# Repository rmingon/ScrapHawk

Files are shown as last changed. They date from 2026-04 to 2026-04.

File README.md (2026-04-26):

# ScrapHawk

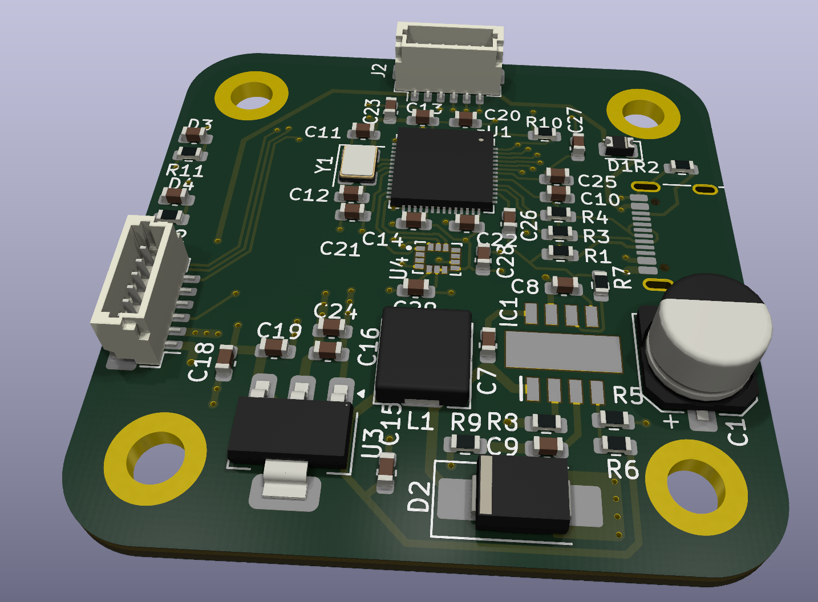
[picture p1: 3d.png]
ScrapHawk Hero Image


*Ultra-budget, high-performance RP2040 flight controller stack bypassing expensive legacy silicon.*

## The Concept: Rethinking the Flight Controller

For years, custom flight controllers have relied on expensive, legacy single-core silicon. ScrapHawk takes a radically different approach. By utilizing the ultra-affordable Raspberry Pi RP2040, modern FreeRTOS Symmetric Multiprocessing (SMP), and hardware-level Programmable I/O (PIO), ScrapHawk delivers a zero-latency, high-performance flight stack on a hacker's budget.

Beyond the silicon, ScrapHawk solves one of the most frustrating problems in drone engineering: Electromagnetic Interference (EMI) from high-current motor ESCs disrupting sensitive navigation sensors. 

To combat this, the ScrapHawk architecture is physically decoupled into two separate printed circuit boards connected by a 6-pin JST-SH (1.0mm) umbilical cable.

---

## Software Architecture: Multi-Core RTOS & PIO Offloading

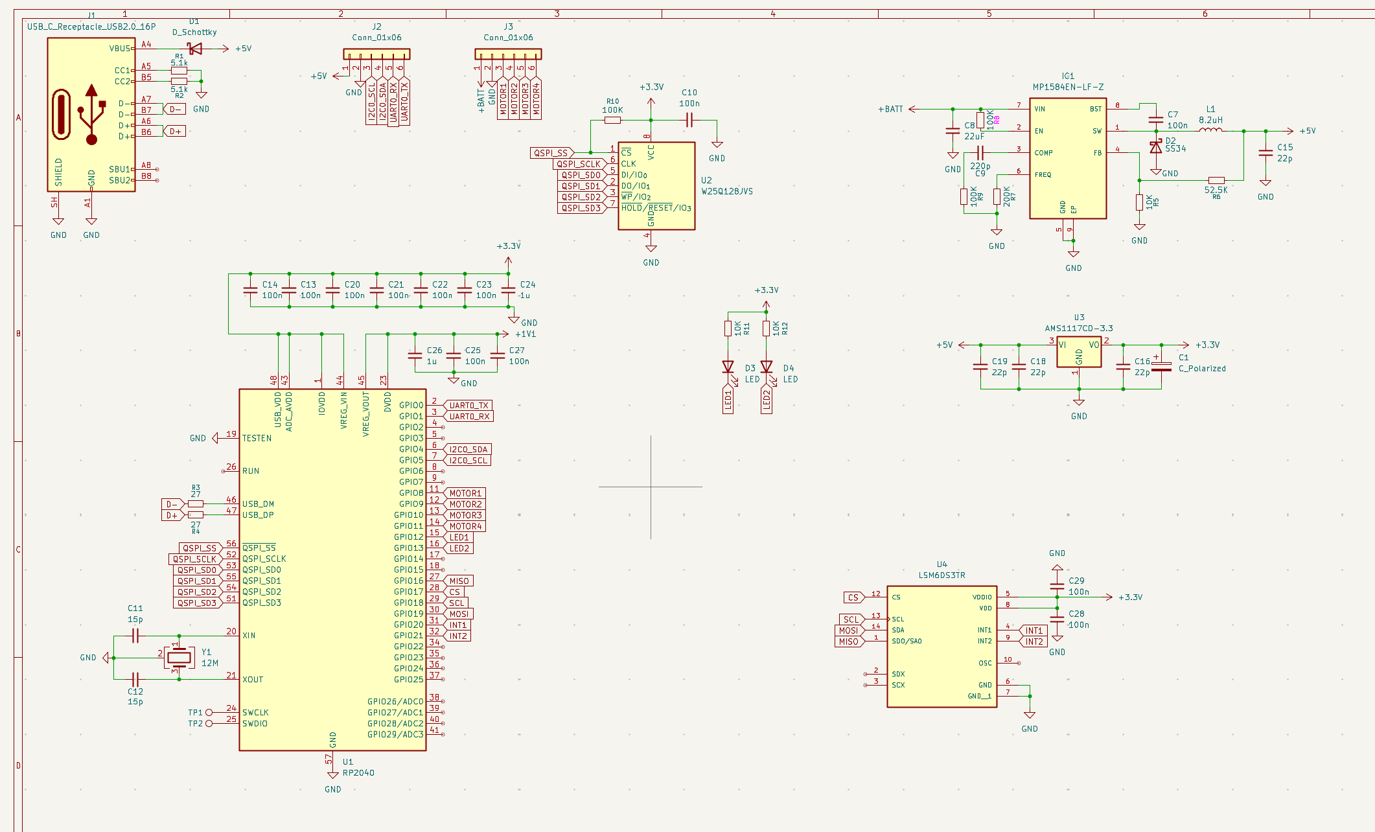
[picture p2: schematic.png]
Software Architecture Diagram


The RP2040 features dual Cortex-M0+ cores. Instead of treating this as a generic processing pool, ScrapHawk leverages FreeRTOS SMP to rigidly enforce core affinity, completely decoupling the real-time flight dynamics from slower, blocking navigation tasks.

### PIO: Zero-Latency Motor Control
Traditionally, generating DSHOT signals for ESCs requires complex timer/DMA configurations that eat up CPU cycles. ScrapHawk completely bypasses the CPU for motor control. By mapping the motor output pins to the RP2040's hardware PIO state machines, the DSHOT timing is handled independently at the hardware level. Core 0 simply pushes throttle values into a FIFO buffer, and the PIO hardware seamlessly clocks out the precise DSHOT pulses.

---

## Hardware Architecture: Split-Board Design

### Board 1: Main FC (The Brain & Muscle)
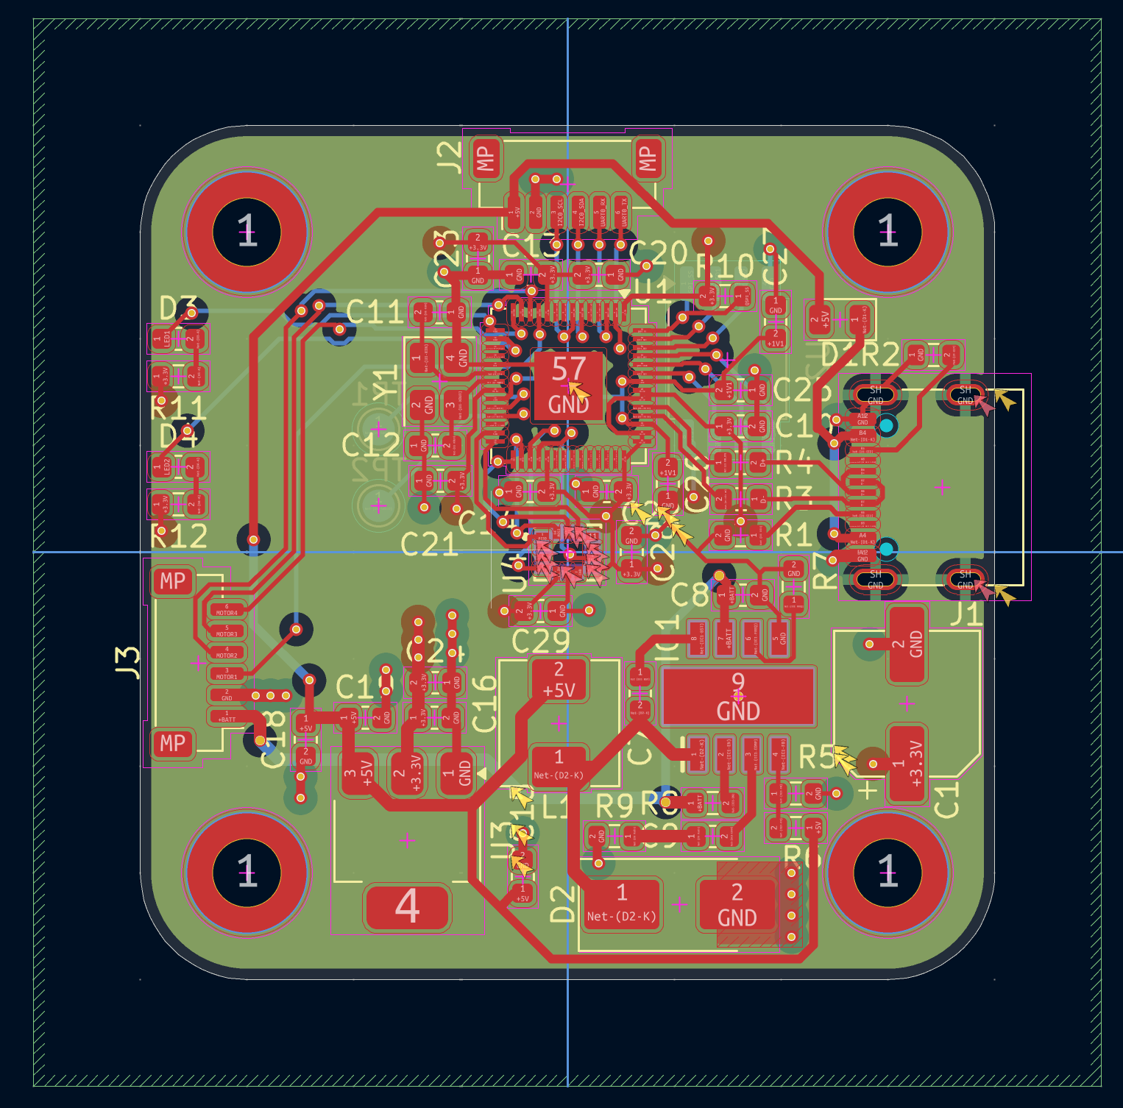
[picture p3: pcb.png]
Main FC Board Render


This is the core flight management and power delivery board, situated in the center of the drone frame.
* **MCU:** Raspberry Pi RP2040 (QFN-56) paired with 16MB QSPI Flash (Winbond W25Q128JVSIQ).
* **IMU:** STMicroelectronics LSM6DS3TR-C, placed precisely at the physical center of the PCB for accurate rotational data. Routed via SPI0 with Data Ready Interrupts.
* **Power Delivery:** A robust dual-stage filter ensures clean power despite ESC noise. A massive 470uF 35V Low-ESR input capacitor feeds a 5V Buck Converter (MP1584EN, 10uH inductor), which then feeds a 3.3V LDO (AMS1117-3.3).
* **Motor & Receiver I/O:** 4 corner ESC solder pads driven by PIO (GPIO 10-13), plus a dedicated 4-pin header for ExpressLRS 2.4GHz receivers via UART1.
* **Connectivity:** USB-C with proper dual 5.1kΩ pull-downs and 27Ω D+/D- series resistors. 
* **The Umbilical:** A 6-pin right-angle SMD connector carrying 5V, GND, UART0 (for GPS), and I2C0 (for Compass). It crucially includes 2.2kΩ pull-up resistors on the I2C lines to maintain signal integrity over the physical wire capacitance.

### Board 2: Nav Puck (The Senses)
Nav Puck Board Render

Designed to be mounted high on a mast, this board keeps the magnetometer and GPS completely isolated from the EMI generated by the motors and power leads.
* **Clean Local Power:** Receives 5V from the umbilical, which is filtered again through a localized AMS1117-3.3 LDO to provide exceptionally clean power exclusively for the sensors.
* **GPS:** Zhongke Micro ATGM336H-5N (UART) equipped with a U.FL connector for an active ceramic patch antenna. It includes an onboard MS621FE 3V backup battery to retain ephemeris data for instant hot-starts.
* **Compass:** QST QMC5883L (I2C) for precise, noise-free heading data.

---

## Who is this for?
ScrapHawk is designed for drone hardware hackers, custom flight controller developers, and FreeRTOS engineers who want to explore modern RTOS paradigms and PIO capabilities without being locked into expensive, proprietary, or legacy ecosystems. It proves that with clever software engineering and thoughtful hardware isolation, cheap silicon can fly just as well—if not better—than the expensive alternatives.

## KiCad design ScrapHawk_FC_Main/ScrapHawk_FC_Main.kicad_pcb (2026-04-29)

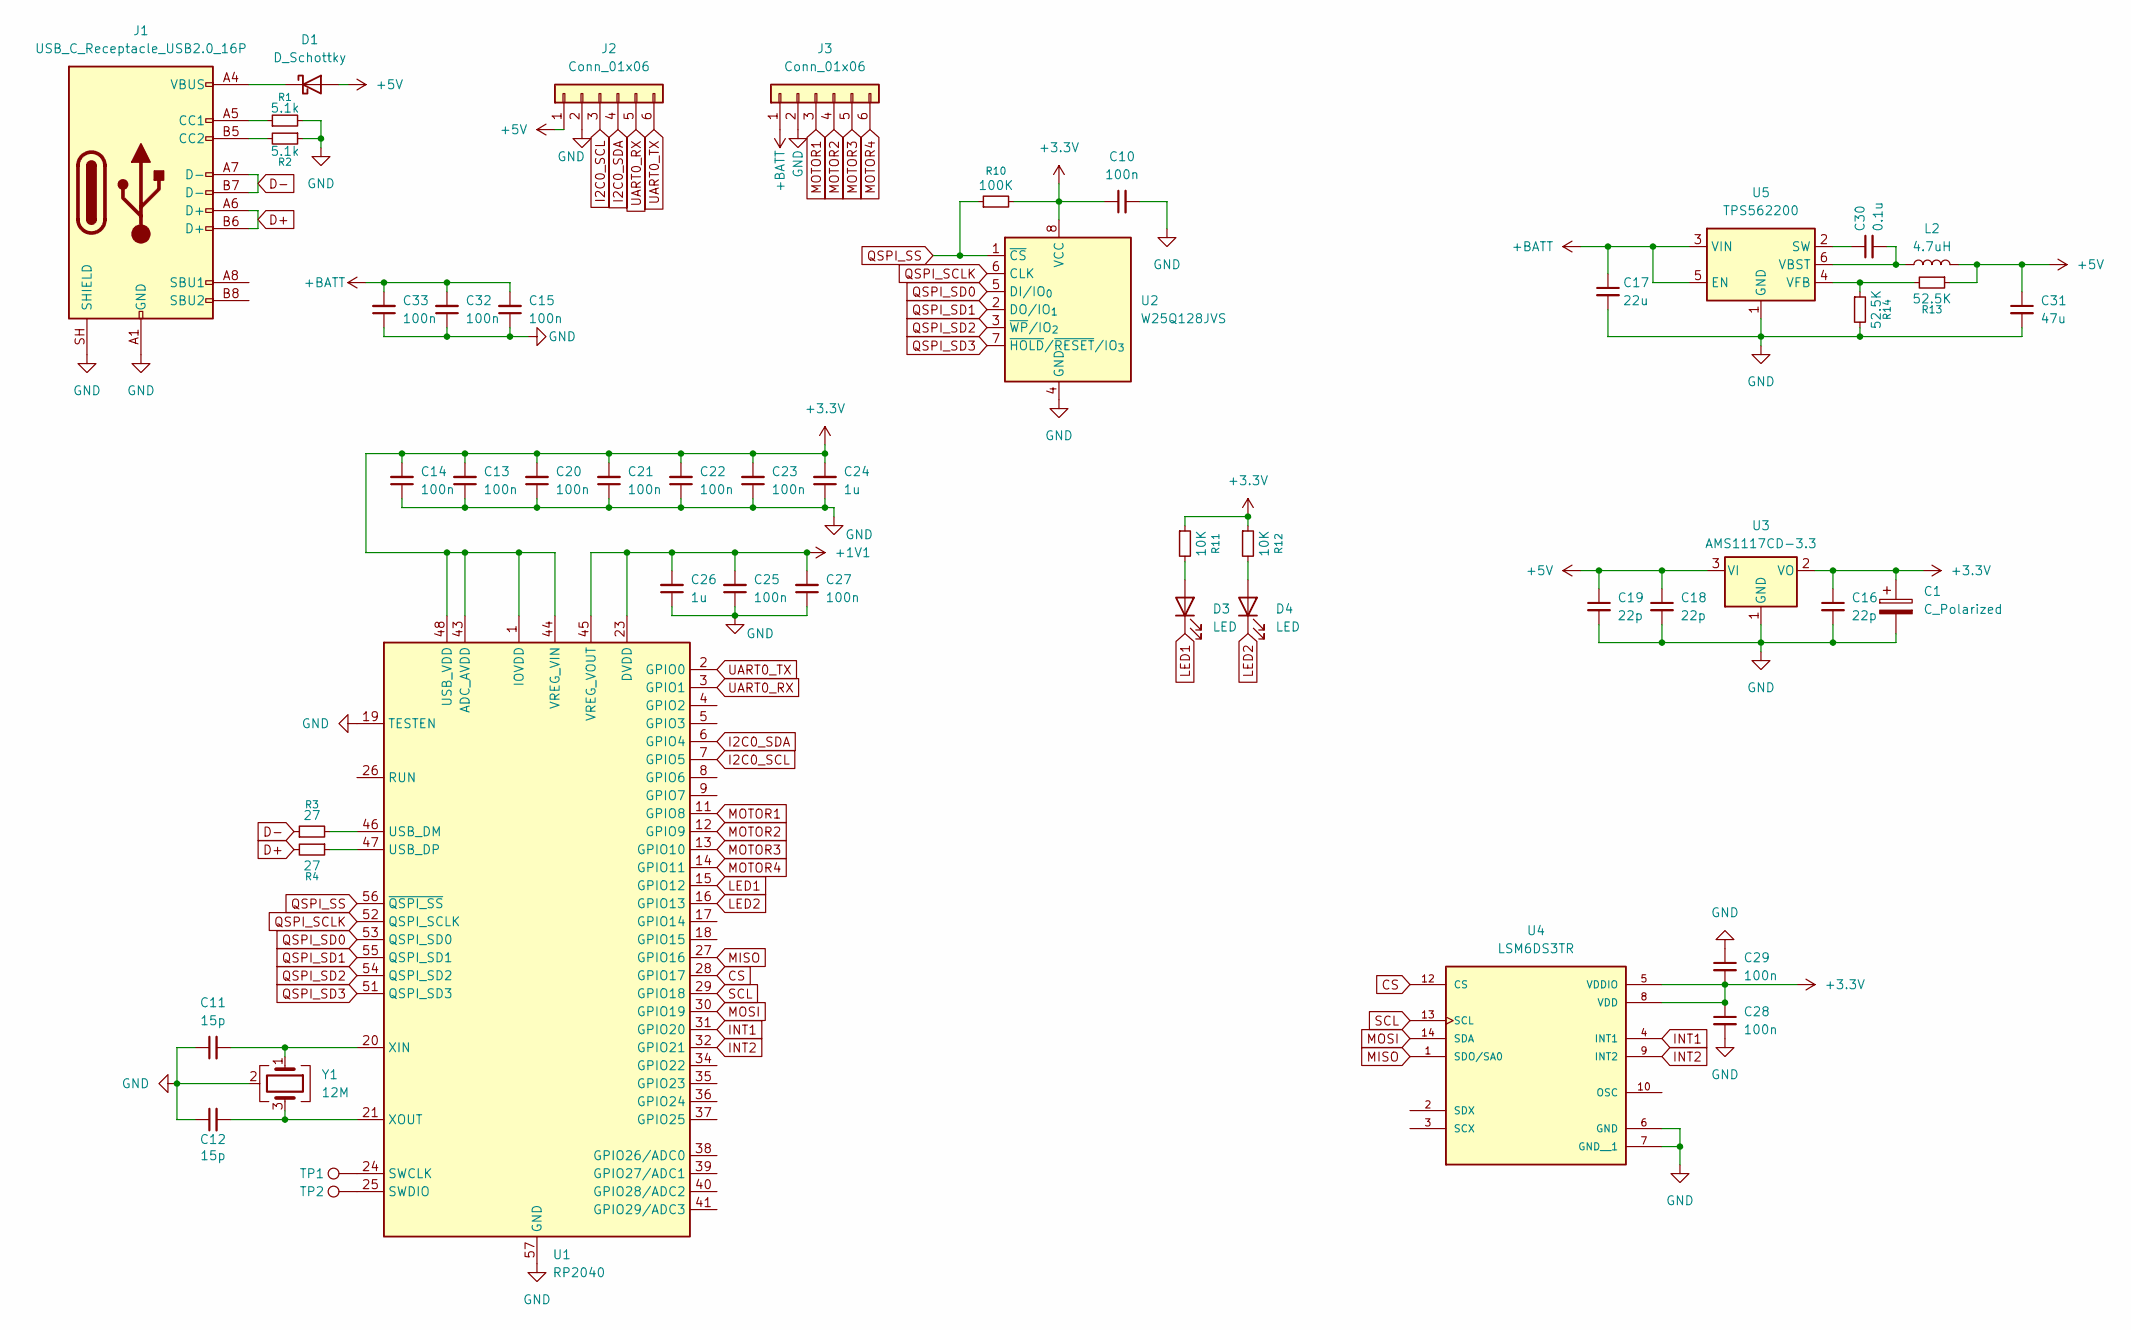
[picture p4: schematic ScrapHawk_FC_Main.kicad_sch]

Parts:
C1: C_Polarized; CP_Elec_6.3x5.2
C10, C13, C14, C20, C21, C22, C23, C25, C27, C28, C29: 100n; C_0603_1608Metric
C11, C12: 15p; C_0603_1608Metric
C15, C32, C33: 100n; C_1206_3216Metric
C16, C18, C19: 22p; C_0603_1608Metric
C17: 22u; C_0603_1608Metric
C24, C26: 1u; C_0603_1608Metric
C30: 0.1u; C_0603_1608Metric
C31: 47u; C_0603_1608Metric
D1: D_Schottky; D_0805_2012Metric
D3, D4: LED; C_0603_1608Metric
J1: USB_C_Receptacle_USB2.0_16P; USB_C_Receptacle_G-Switch_GT-USB-7010ASV
J2, J3: Conn_01x06; JST_SH_BM06B-SRSS-TB_1x06-1MP_P1.00mm_Vertical
L2: 4.7uH; L_Chilisin_BMRA00050520
R1, R2: 5.1k; R_0603_1608Metric
R3, R4: 27; R_0603_1608Metric
R10: 100K; R_0603_1608Metric
R11, R12: 10K; R_0603_1608Metric
R13, R14: 52.5K; R_0603_1608Metric
TP1, TP2: TestPoint; TestPoint_Pad_D1.5mm
U1: RP2040; QFN-56-1EP_7x7mm_P0.4mm_EP3.2x3.2mm
U2: W25Q128JVS; SOIC-8_5.3x5.3mm_P1.27mm
U3: AMS1117CD-3.3; SOT-223
U4: LSM6DS3TR; PQFN50P300X250X86-14N; PARTREV 2
U5: TPS562200; SOT-23-6
Y1: 12M; Crystal_SMD_SeikoEpson_TSX3225-4Pin_3.2x2.5mm

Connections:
+1V1: C25.2, C26.2, C27.2, U1.23 (DVDD), U1.45 (VREG_VOUT), U1.50 (DVDD)
+3.3V: C1.1, C10.1, C13.2, C14.2, C16.1, C20.2, C21.2, C22.2, C23.2, C24.2, C28.1, C29.2, R10.2, R11.1, R12.1, U1.1 (IOVDD), U1.10 (IOVDD), U1.22 (IOVDD), U1.33 (IOVDD), U1.42 (IOVDD), U1.43 (ADC_AVDD), U1.44 (VREG_VIN), U1.48 (USB_VDD), U1.49 (IOVDD), U2.8 (VCC), U3.2 (VO), U4.5 (VDDIO), U4.8 (VDD)
+5V: C18.1, C19.1, C31.1, D1.2 (A), J2.1, L2.2, R13.1, U3.3 (VI)
+BATT: C15.2, C17.1, C32.2, C33.2, J3.1, U5.3 (VIN), U5.5 (EN)
CS: U1.28 (GPIO17), U4.12 (CS)
D+: J1.A6 (D+), J1.B6 (D+), R4.2
D-: J1.A7 (D-), J1.B7 (D-), R3.1
GND: C1.2, C10.2, C11.1, C12.1, C13.1, C14.1, C15.1, C16.2, C17.2, C18.2, C19.2, C20.1, C21.1, C22.1, C23.1, C24.1, C25.1, C26.1, C27.1, C28.2, C29.1, C31.2, C32.1, C33.1, J1.A1 (GND), J1.A12 (GND), J1.B1 (GND), J1.B12 (GND), J1.SH (SHIELD), J2.2, J3.2, R1.2, R2.1, R14.2, U1.19 (TESTEN), U1.57 (GND), U2.4 (GND), U3.1 (GND), U4.6 (GND), U4.7 (GND__1), U5.1 (GND), Y1.2 (G), Y1.4 (G)
I2C0_SCL: J2.3, U1.7 (GPIO5)
I2C0_SDA: J2.4, U1.6 (GPIO4)
INT1: U1.31 (GPIO20), U4.4 (INT1)
INT2: U1.32 (GPIO21), U4.9 (INT2)
LED1: D3.1 (K), U1.15 (GPIO12)
LED2: D4.1 (K), U1.16 (GPIO13)
MISO: U1.27 (GPIO16), U4.1 (SDO/SA0)
MOSI: U1.30 (GPIO19), U4.14 (SDA)
MOTOR1: J3.3, U1.11 (GPIO8)
MOTOR2: J3.4, U1.12 (GPIO9)
MOTOR3: J3.5, U1.13 (GPIO10)
MOTOR4: J3.6, U1.14 (GPIO11)
unnamed: D1.1 (K), J1.A4 (VBUS), J1.A9 (VBUS), J1.B4 (VBUS), J1.B9 (VBUS)
unnamed: D3.2 (A), R11.2
unnamed: D4.2 (A), R12.2
unnamed: J1.A5 (CC1), R1.1
unnamed: J1.B5 (CC2), R2.2
unnamed: TP1.1 (1_1), U1.24 (SWCLK)
unnamed: TP2.1 (1_1), U1.25 (SWDIO)
unnamed: R3.2, U1.46 (USB_DM)
unnamed: R4.1, U1.47 (USB_DP)
unnamed: C11.2, U1.20 (XIN), Y1.1
unnamed: C12.2, U1.21 (XOUT), Y1.3
unnamed: C30.1, U5.2 (SW)
unnamed: C30.2, L2.1, U5.6 (VBST)
unnamed: R13.2, R14.1, U5.4 (VFB)
QSPI_SCLK: U1.52 (QSPI_SCLK), U2.6 (CLK)
QSPI_SD0: U1.53 (QSPI_SD0), U2.5 (DI/IO_{0})
QSPI_SD1: U1.55 (QSPI_SD1), U2.2 (DO/IO_{1})
QSPI_SD2: U1.54 (QSPI_SD2), U2.3 (~WP/IO_{2})
QSPI_SD3: U1.51 (QSPI_SD3), U2.7 (~HOLD/~RESET/IO_{3})
QSPI_SS: R10.1, U1.56 (~QSPI_SS), U2.1 (~CS)
SCL: U1.29 (GPIO18), U4.13 (SCL)
UART0_RX: J2.5, U1.3 (GPIO1)
UART0_TX: J2.6, U1.2 (GPIO0)

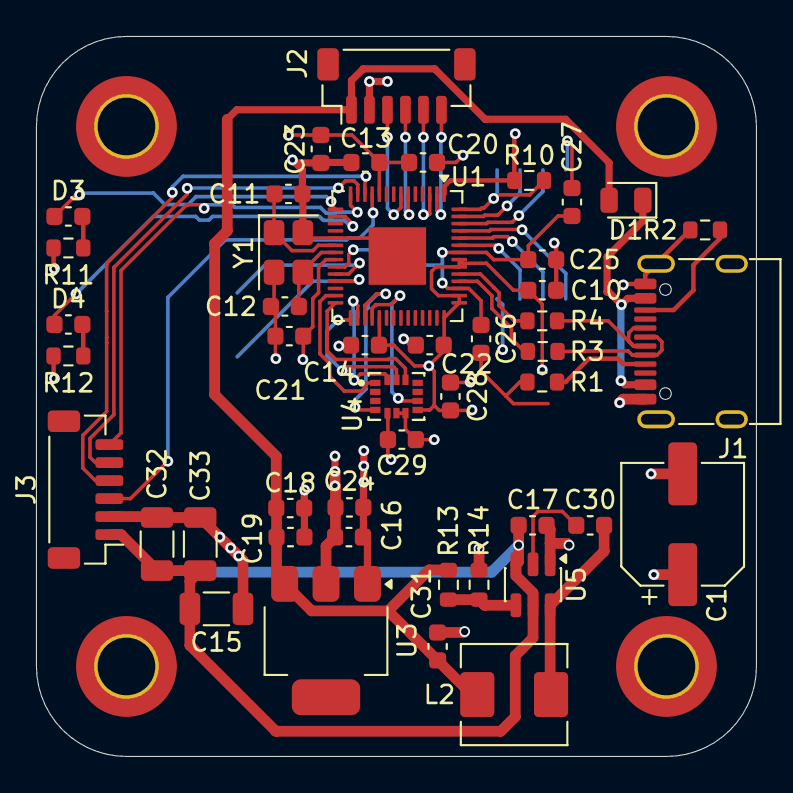
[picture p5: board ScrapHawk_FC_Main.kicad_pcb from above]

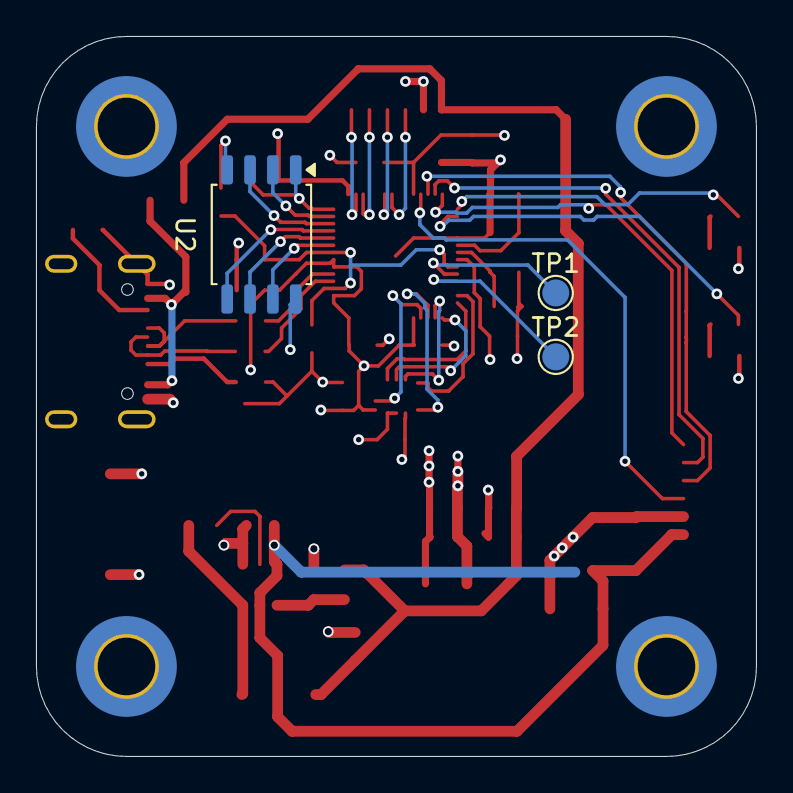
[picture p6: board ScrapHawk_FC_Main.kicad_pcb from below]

Board: 4 copper layers, 40.0 x 40.0 mm, 49 parts (3 on the bottom side), 43 nets.

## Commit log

2026-04-19 add kicad ignore files
2026-04-19 add flash - rp2040 wire
    [ScrapHawk_FC_Main.kicad_sch]
2026-04-19 add step down + usb c connector wire
    [ScrapHawk_FC_Main.kicad_sch]
2026-04-19 update gyro
    [ScrapHawk_FC_Main.kicad_pcb, ScrapHawk_FC_Main.kicad_sch]
2026-04-20 wire pcb place components
    [ScrapHawk_FC_Main.kicad_pcb, ScrapHawk_FC_Main.kicad_sch]
2026-04-26 finish pcb wiring
    [ScrapHawk_FC_Main.kicad_pcb, ScrapHawk_FC_Main.kicad_sch]
2026-04-26 fix capacitors size
    [ScrapHawk_FC_Main.kicad_pcb, ScrapHawk_FC_Main.kicad_sch]
2026-04-26 update capacitor
    [ScrapHawk_FC_Main.kicad_pcb, ScrapHawk_FC_Main.kicad_sch]
2026-04-29 update stepdown
    [ScrapHawk_FC_Main.kicad_pcb, ScrapHawk_FC_Main.kicad_sch]
2026-04-29 update decoupling capacitor battery
    [ScrapHawk_FC_Main.kicad_pcb, ScrapHawk_FC_Main.kicad_sch]
